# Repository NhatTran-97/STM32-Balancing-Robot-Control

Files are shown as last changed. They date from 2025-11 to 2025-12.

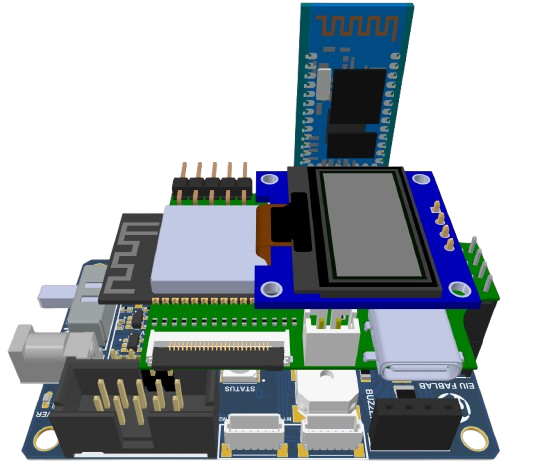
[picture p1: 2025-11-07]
prefix/images/Screenshot_2025-09-14_141622-removebg-preview.png

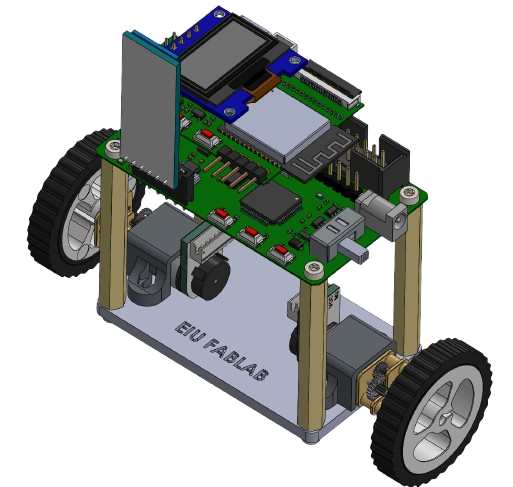
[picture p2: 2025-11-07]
prefix/images/Screenshot_2025-09-14_212536-removebg-preview.png

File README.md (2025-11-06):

# STM32 Self-Balancing Control

A self-balancing robot based on the **STM32 microcontroller**, implementing both **PID** and **LQR** control algorithms.
This project also applies **signal filtering** techniques to improve sensor accuracy and control stability:

* **Moving Average Filter** for encoder smoothing
* **Complementary Filter** for IMU fusion (gyroscope + accelerometer)

---

## 🧭 Overview

This project demonstrates the design of a **self-balancing two-wheel robot** using an STM32 MCU.
It integrates:

* Real-time angle estimation with IMU sensors
* Encoder feedback for wheel speed
* Dual control strategies (PID and LQR)
* Data filtering for smoother, more accurate control
---

## ⚙️ System Architecture / Kiến trúc hệ thống

```
[ Encoder ] ---> [ Moving Average Filter ] ---> [ Wheel Speed ]
                      ↓
[ IMU (Gyro + Accel) ] ---> [ Complementary Filter ] ---> [ Tilt Angle θ, θ_dot ]
                      ↓
            [ PID / LQR Controller ]
                      ↓
             [ PWM Output to Motors ]
```

---

## 🧩 Features

| Module | Description | Mô tả |
| :--- | :--- | :--- |
| **Encoder Filtering** | Moving Average Filter to smooth velocity readings  | Bộ lọc trung bình trượt làm mượt dữ liệu encoder |
| **Angle Estimation**  | Complementary Filter combining gyro & accel | Bộ lọc bổ sung hợp nhất gyro và accelerometer |
| **PID Control** | Classic feedback control for balance | Điều khiển phản hồi cổ điển PID |
| **LQR Control** | Optimal control minimizing system energy | Điều khiển tối ưu hóa năng lượng hệ thống |
| **Visualization** | Serial plotting / Python interface for angle & PWM | Giao diện hiển thị qua Serial/Python để giám sát góc và PWM |

---

## 🧠 Control Algorithms

### 1. PID Control

[
u = K_p e + K_i \int e ,dt + K_d \frac{de}{dt}
]

### 2. LQR Control

[
u = -Kx
]
where ( x = [\theta, \dot{\theta}, v, \dot{v}]^T )

---

## 🔧 Hardware Setup 

| Component | Description |
| :--- | :--- |
| MCU | STM32L476RGT6 series |
| IMU | ICM20948 |
| Motor Driver | STSP240 |
| Encoders | DC motor encoders (e.g., 11 PPR) |
| Power | 2S/3S LiPo battery |
| Frame | Two-wheel balancing chassis |

---

## 📂 Project Structure

```
STM32-Self-Balancing-Control/
├── Core/
│   ├── Src/
│   ├── Inc/
│   └── main.c
├── Drivers/
├── Filters/
│   ├── moving_average.c
│   └── complementary_filter.c
├── Control/
│   ├── pid.c
│   └── lqr.c
├── Utils/
│   └── encoder.c
├── README.md
```

---

## 🧪 Implementation Notes / Ghi chú triển khai

* Sampling period: 10 ms (100 Hz loop)
* Complementary filter α = 0.98
* Moving average window = 10 samples
* PID gains tuned manually via step response
* LQR gains obtained from linearised model in MATLAB

---

## 🧰 Build & Flash

**Toolchain:** STM32CubeIDE / PlatformIO
**Steps:**

1. Clone this repository

   ```bash
   git clone https://github.com/NhatTran-97/STM32-Self-Balancing-Control.git
   ```
2. Open project in STM32CubeIDE
3. Build and flash firmware to STM32 board
4. Connect via UART/USB to monitor data

---

## 🎥 Demo (optional placeholder)

> *Add a GIF or image of the balancing robot here*
>
> Ví dụ: ảnh robot đang tự cân bằng hoặc biểu đồ góc nghiêng.

---

## 📚 References 

* [Complementary Filter explained](https://www.pieter-jan.com/node/11)
* [LQR Design for Inverted Pendulum](https://ctms.engin.umich.edu/CTMS/index.php?example=InvertedPendulum&section=ControlStateSpace)
* STM32Cube HAL documentation
* ICM20948 datasheet

---

**Author:** [NhatTran-97](https://github.com/NhatTran-97)
**License:** MIT License

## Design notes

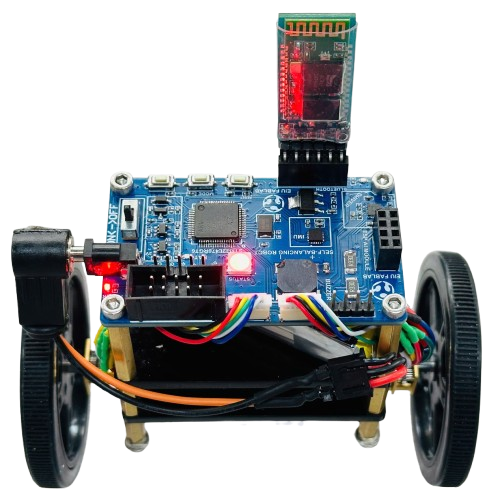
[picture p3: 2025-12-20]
prefix/images/robot_balancing.png

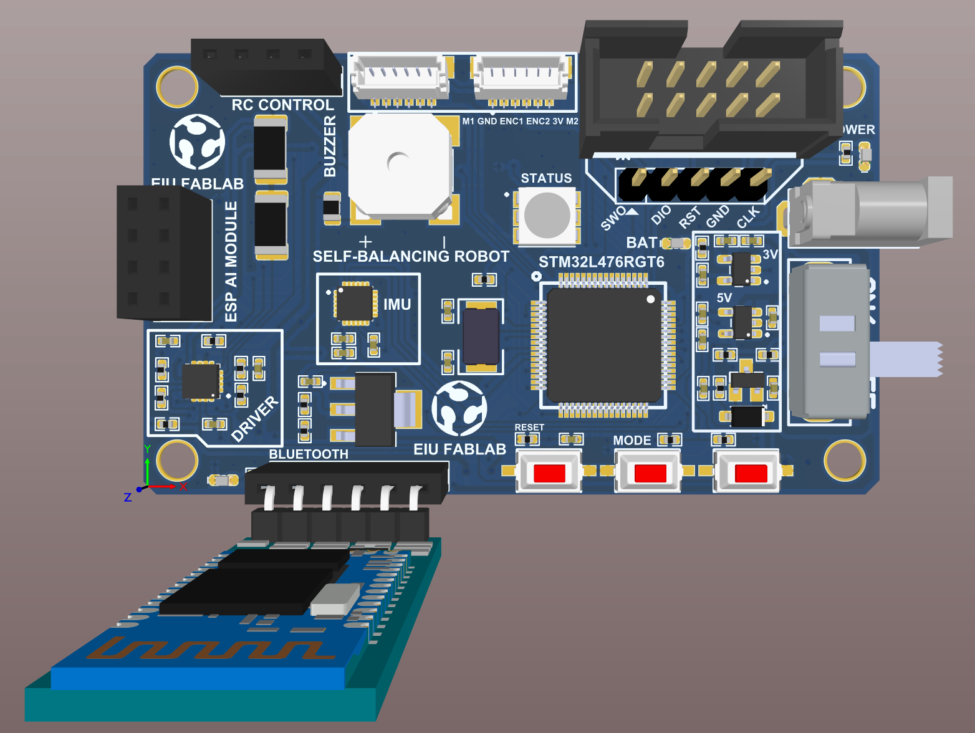
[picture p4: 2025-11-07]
prefix/images/Screenshot 2025-09-14 213541.png

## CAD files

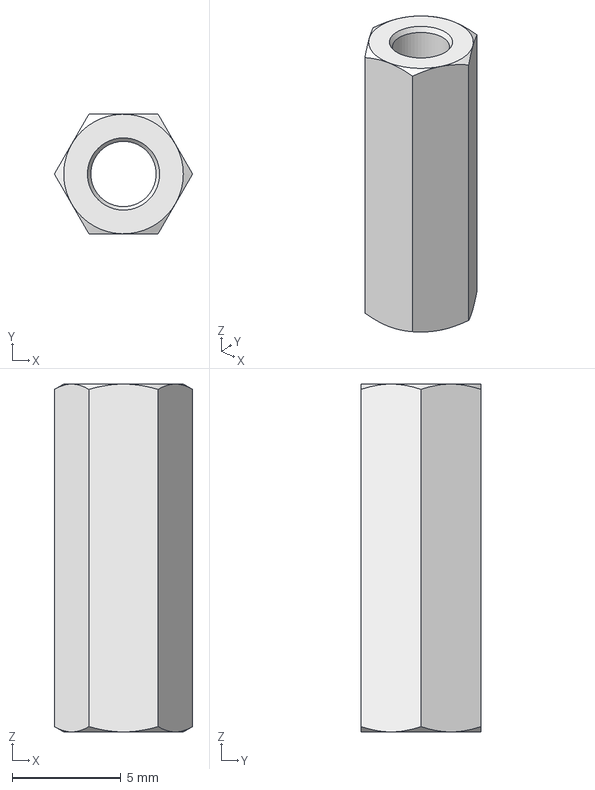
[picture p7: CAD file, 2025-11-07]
3D_Balancing_Robot/hexagonal-spacers-m3-f-f-hex-5-5-1.snapshot.1/hexagonal_spacer_FF_M3_H16_HEX5.5_pass_through.step
6.36 x 5.51 x 16.0 mm

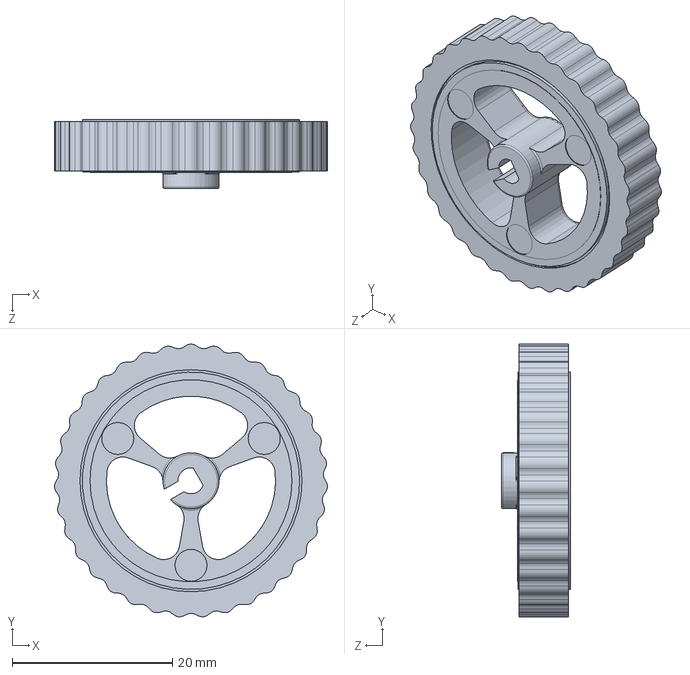
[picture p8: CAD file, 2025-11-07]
3D_Balancing_Robot/llanta-para-motor-n20-32x7mm-blanca-1.snapshot.1/Llanta.SLDPRT
34.1 x 34.0 x 8.65 mm

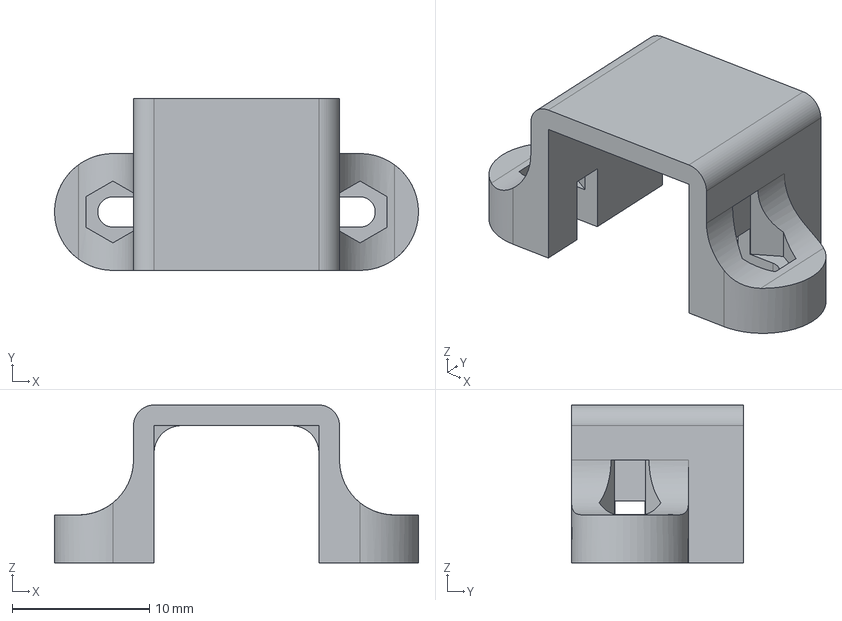
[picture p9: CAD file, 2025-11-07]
3D_Balancing_Robot/n20-motor-mount-2.snapshot.1/motor mount-Body.step
26.5 x 12.5 x 11.5 mm

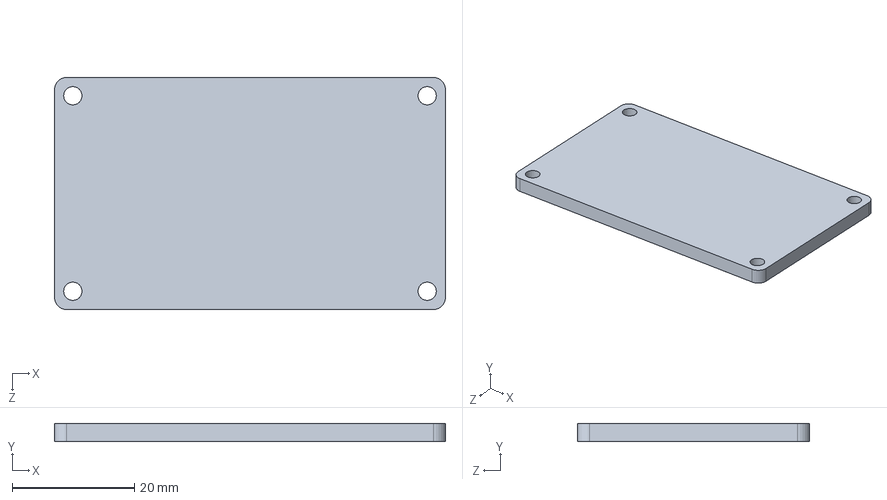
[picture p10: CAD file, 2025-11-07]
3D_Balancing_Robot/Part2.SLDPRT
64.0 x 3.00 x 38.0 mm

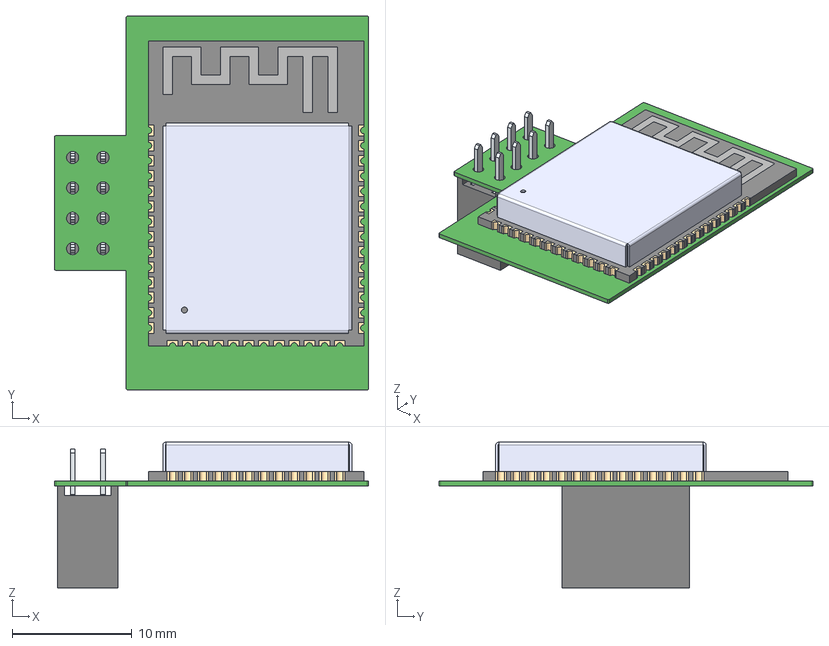
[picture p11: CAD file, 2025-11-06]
PCB_ESP32_Dev/3D/ESP32_DEV.step
26.3 x 31.3 x 12.2 mm
Board
6130xx21821_PIN x 8

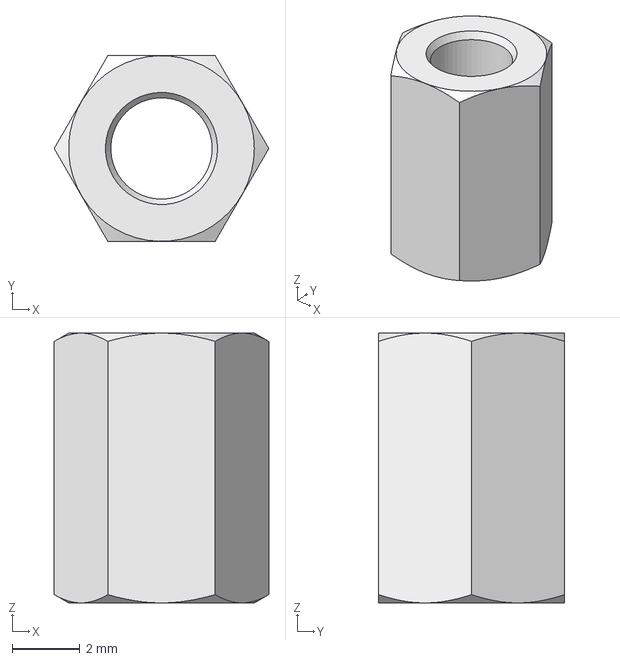
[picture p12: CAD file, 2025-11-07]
3D_Balancing_Robot/hexagonal-spacers-m3-f-f-hex-5-5-1.snapshot.1/hexagonal_spacer_FF_M3_H08_HEX5.5_pass_through.step
6.36 x 5.51 x 8.00 mm

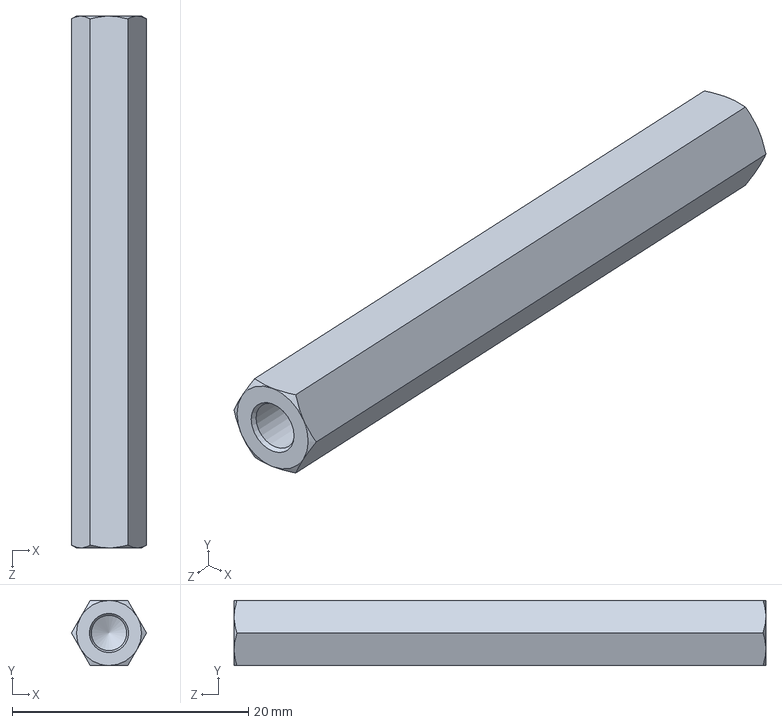
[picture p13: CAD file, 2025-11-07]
3D_Balancing_Robot/hexagonal_spacer_FF_M3_H45_HEX5.5_FTD0.SLDPRT
6.36 x 5.51 x 45.0 mm

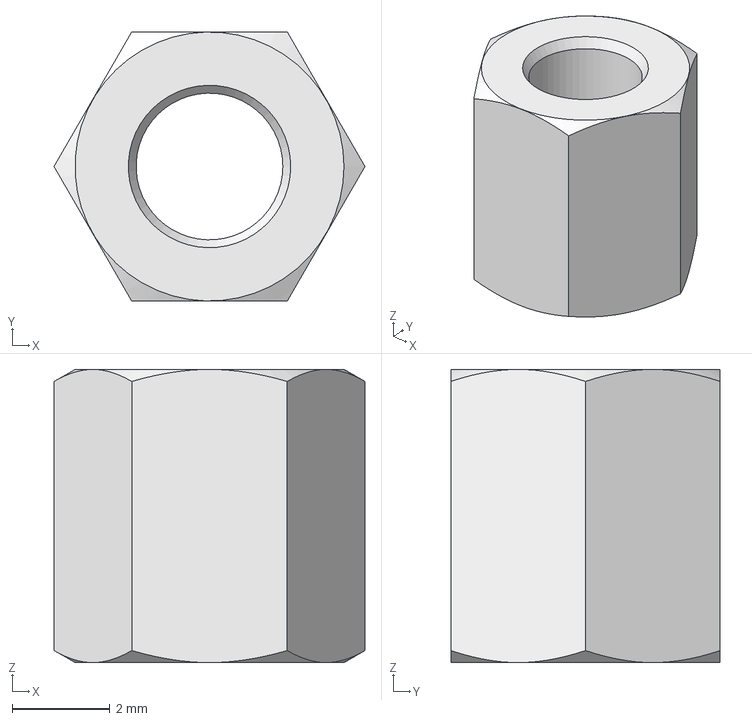
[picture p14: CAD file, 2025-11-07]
3D_Balancing_Robot/hexagonal-spacers-m3-f-f-hex-5-5-1.snapshot.1/hexagonal_spacer_FF_M3_H06_HEX5.5_pass_through.step
6.36 x 5.51 x 6.00 mm

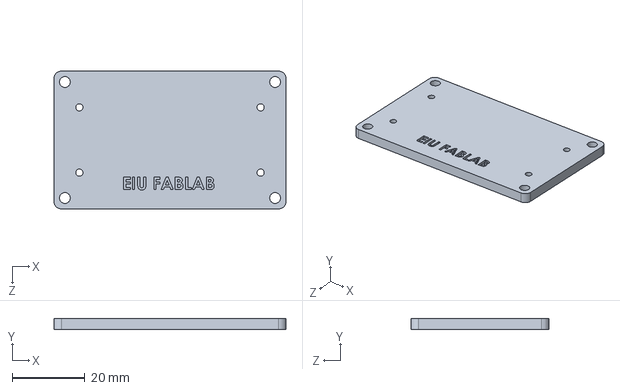
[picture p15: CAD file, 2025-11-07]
3D_Balancing_Robot/Part1.SLDPRT
64.0 x 3.00 x 38.0 mm

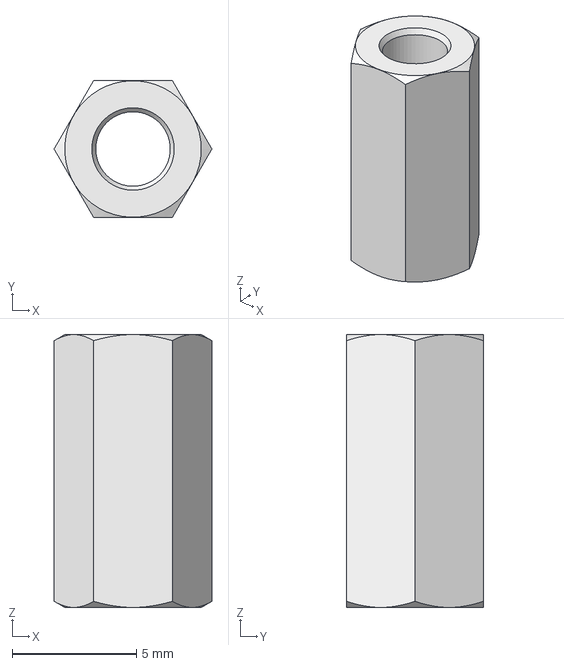
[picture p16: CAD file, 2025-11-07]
3D_Balancing_Robot/hexagonal-spacers-m3-f-f-hex-5-5-1.snapshot.1/hexagonal_spacer_FF_M3_H11_HEX5.5_pass_through.step
6.36 x 5.51 x 11.0 mm

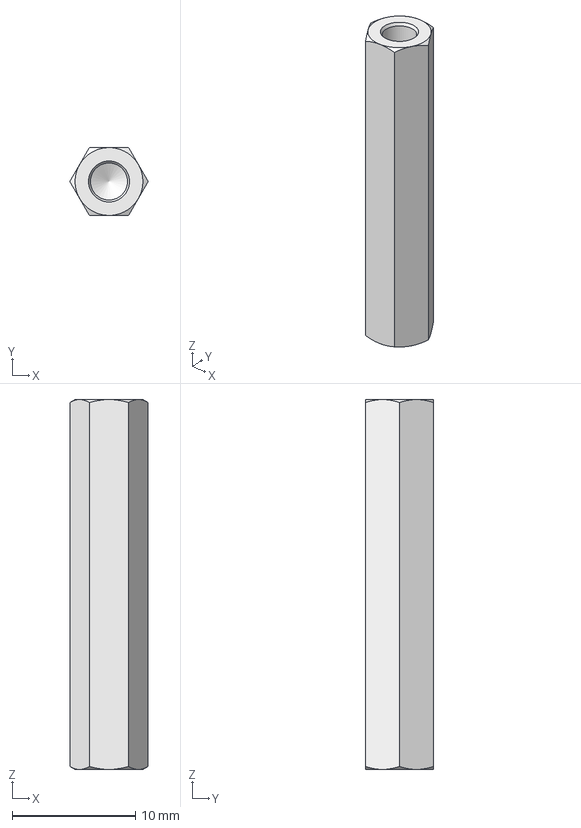
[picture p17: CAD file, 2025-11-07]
3D_Balancing_Robot/hexagonal-spacers-m3-f-f-hex-5-5-1.snapshot.1/hexagonal_spacer_FF_M3_H30_HEX5.5_FTD10.step
6.36 x 5.51 x 30.0 mm

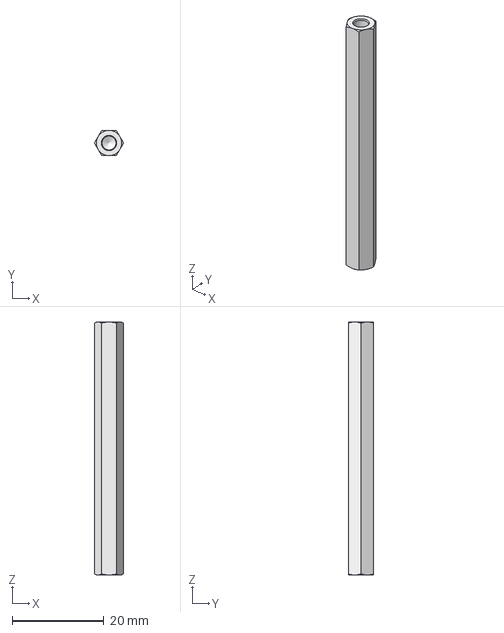
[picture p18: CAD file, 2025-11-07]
3D_Balancing_Robot/hexagonal-spacers-m3-f-f-hex-5-5-1.snapshot.1/hexagonal_spacer_FF_M3_H55_HEX5.5_FTD10.step
6.36 x 5.51 x 55.0 mm

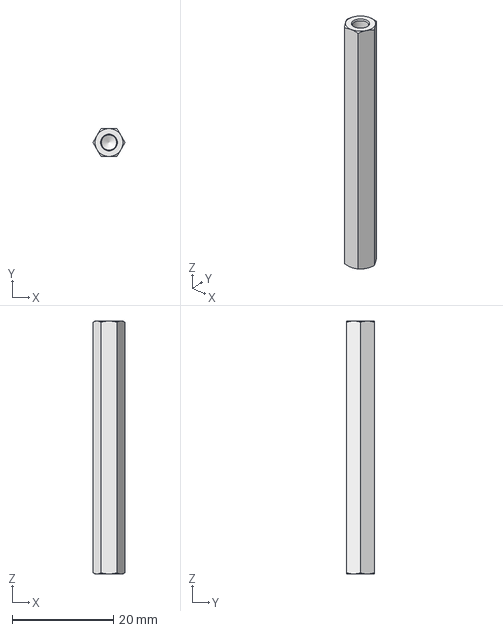
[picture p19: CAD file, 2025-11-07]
3D_Balancing_Robot/hexagonal-spacers-m3-f-f-hex-5-5-1.snapshot.1/hexagonal_spacer_FF_M3_H50_HEX5.5_FTD10.step
6.36 x 5.51 x 50.0 mm

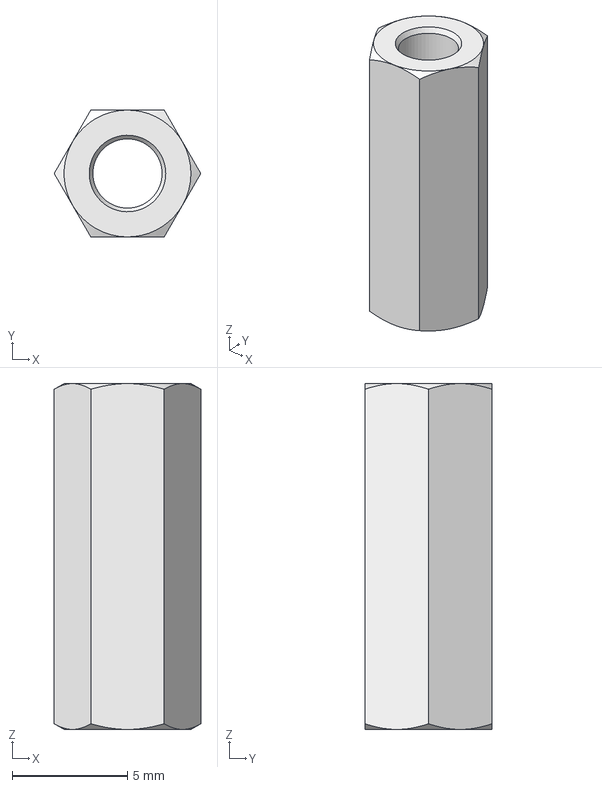
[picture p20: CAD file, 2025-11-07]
3D_Balancing_Robot/hexagonal-spacers-m3-f-f-hex-5-5-1.snapshot.1/hexagonal_spacer_FF_M3_H15_HEX5.5_pass_through.step
6.36 x 5.51 x 15.0 mm

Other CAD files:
3D_Balancing_Robot/llanta-para-motor-n20-32x7mm-blanca-1.snapshot.1/Llanta1.SLDPRT
3D_Balancing_Robot/hexagonal_spacer_FF_M3_H45_HEX5.5_FTD10.SLDPRT
3D_Balancing_Robot/hexagonal-spacers-m3-f-f-hex-5-5-1.snapshot.1/hexagonal_spacer_FF_M3_H18_HEX5.5_pass_through.step
3D_Balancing_Robot/hexagonal-spacers-m3-f-f-hex-5-5-1.snapshot.1/hexagonal_spacer_FF_M3_H45_HEX5.5_FTD10.step
3D_Balancing_Robot/hexagonal-spacers-m3-f-f-hex-5-5-1.snapshot.1/hexagonal_spacer_FF_M3_H04_HEX5.5_pass_through.step
3D_Balancing_Robot/hexagonal-spacers-m3-f-f-hex-5-5-1.snapshot.1/hexagonal_spacer_FF_M3_H05_HEX5.5_pass_through.step
3D_Balancing_Robot/hexagonal-spacers-m3-f-f-hex-5-5-1.snapshot.1/hexagonal_spacer_FF_M3_H07_HEX5.5_pass_through.step
3D_Balancing_Robot/hexagonal-spacers-m3-f-f-hex-5-5-1.snapshot.1/hexagonal_spacer_FF_M3_H09_HEX5.5_pass_through.step
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

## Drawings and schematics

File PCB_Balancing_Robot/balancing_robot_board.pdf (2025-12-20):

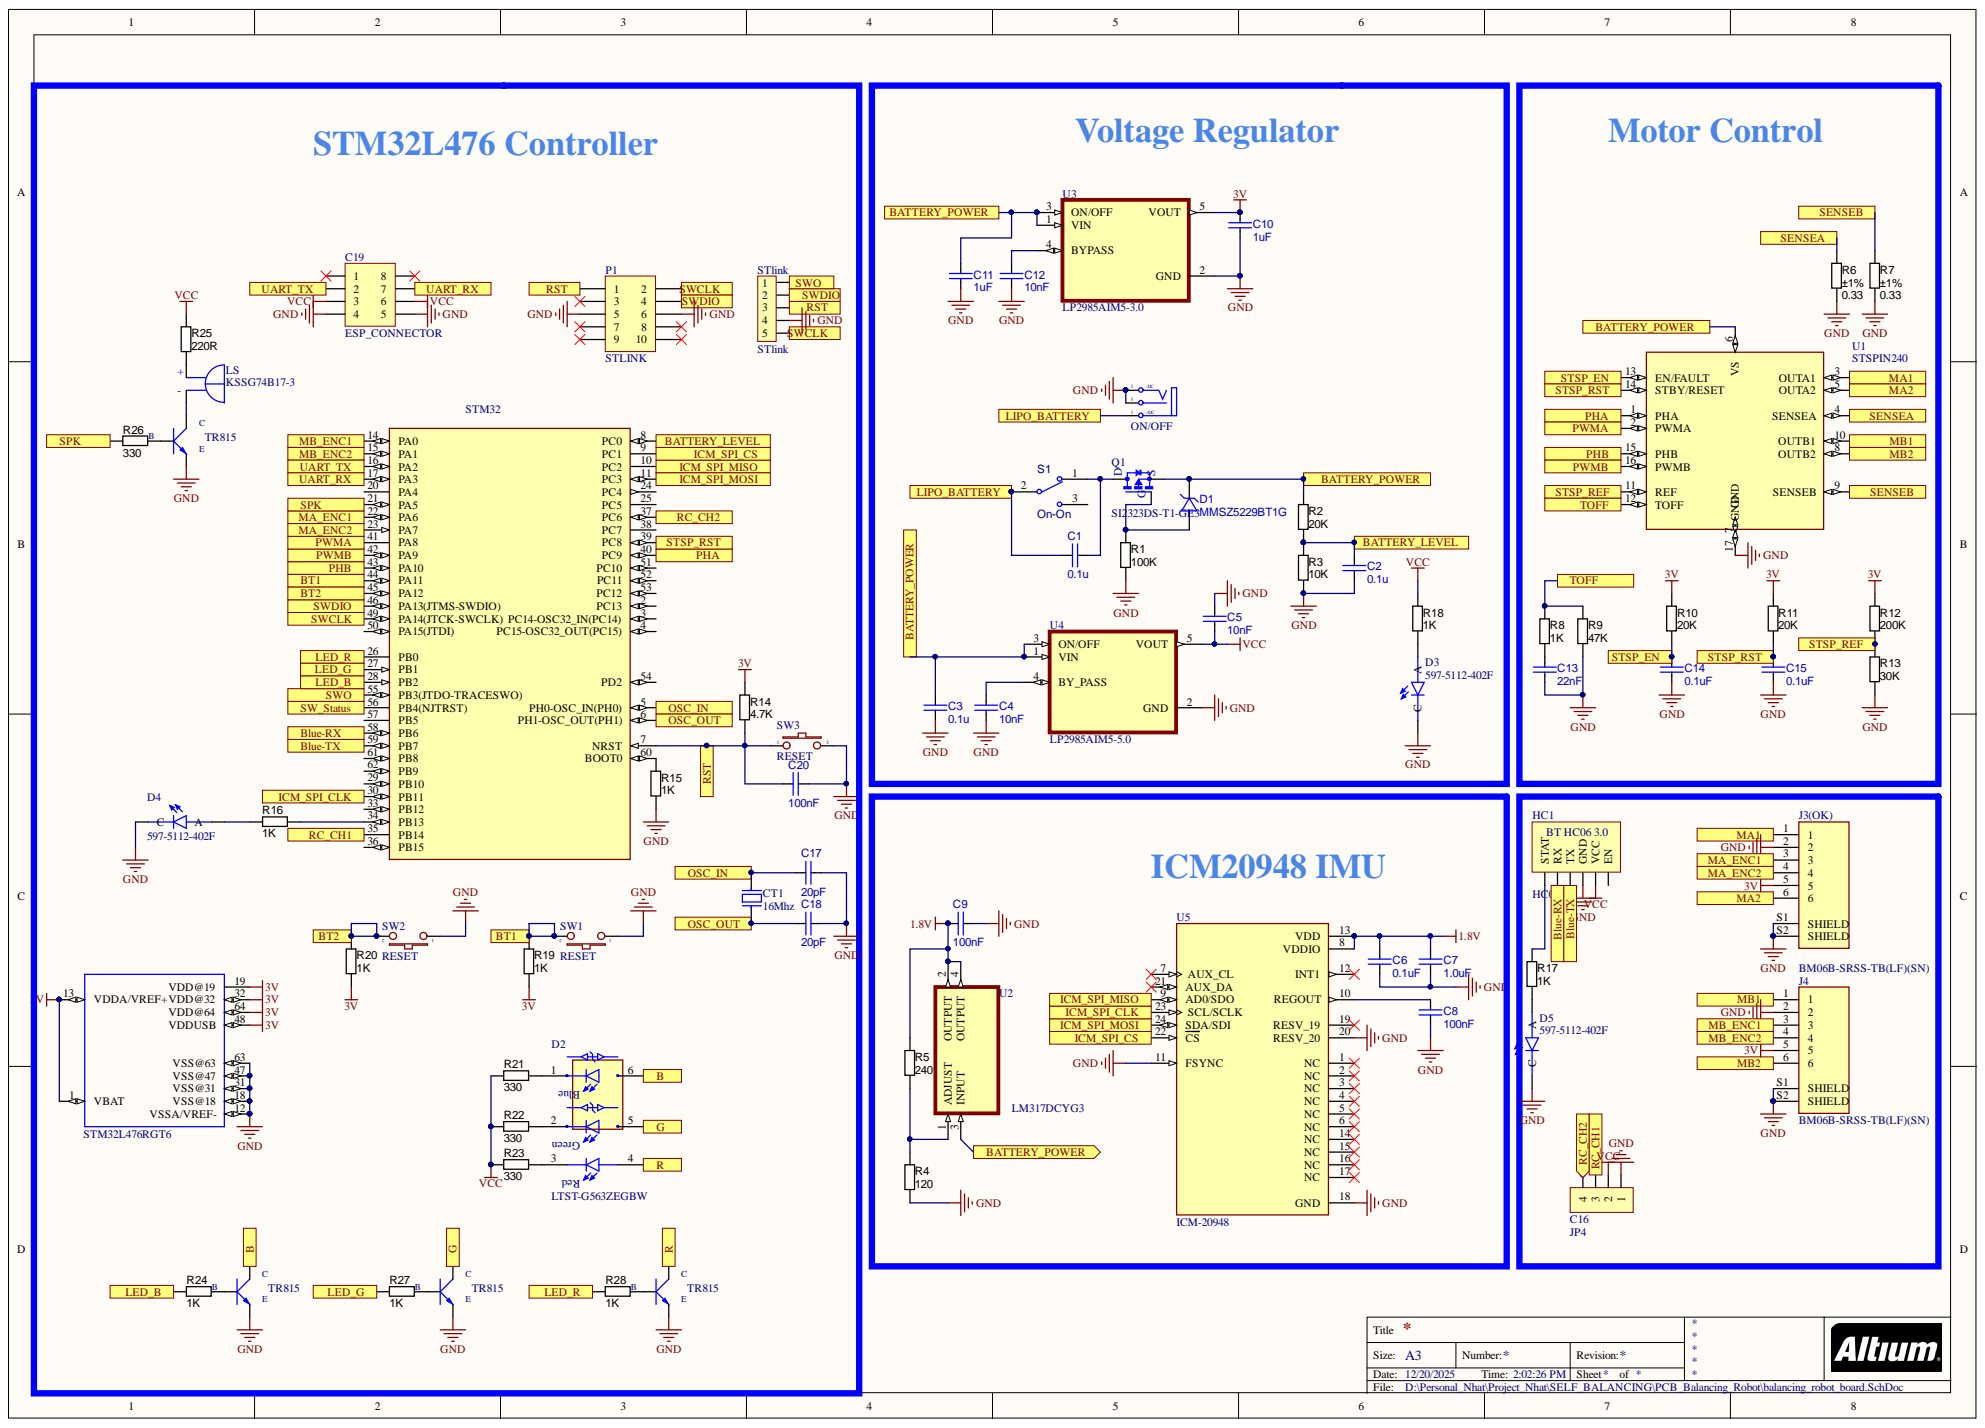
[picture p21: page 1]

STSP_EN | STBY/RESET 14 | MA1
STSP_RST | PHA 1 | MA2

VIN 1

LED_G | PB2 28
LED_B | PB3(JTDO-TRACESWO) 55
SWO | PB4(NJTRST) 56

Blue-RX | PB7 59

MA_ENC1 | 4 4

BM06B-SRSS-TB(LF)(SN)

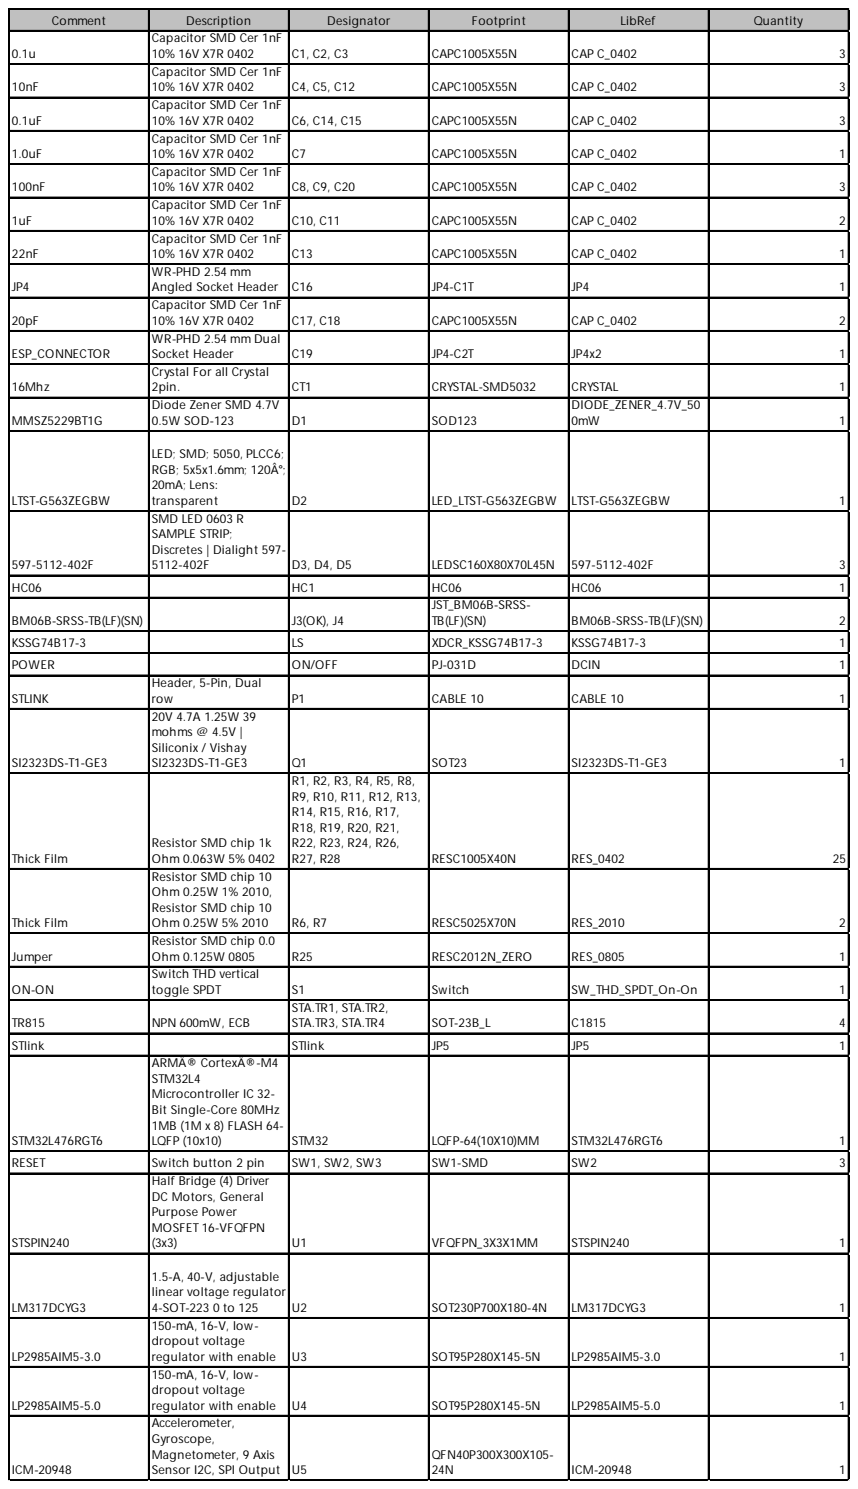
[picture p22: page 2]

Comment | Description | Designator | Footprint | LibRef | Quantity

0.1u | Capacitor SMD Cer 1nF 10% 16V X7R 0402 | C1, C2, C3 | CAPC1005X55N | CAP C_0402 | 3

10nF | Capacitor SMD Cer 1nF 10% 16V X7R 0402 | C4, C5, C12 | CAPC1005X55N | CAP C_0402 | 3

0.1uF | Capacitor SMD Cer 1nF 10% 16V X7R 0402 | C6, C14, C15 | CAPC1005X55N | CAP C_0402 | 3

1.0uF | Capacitor SMD Cer 1nF 10% 16V X7R 0402 | C7 | CAPC1005X55N | CAP C_0402 | 1

100nF | Capacitor SMD Cer 1nF 10% 16V X7R 0402 | C8, C9, C20 | CAPC1005X55N | CAP C_0402 | 3

1uF | Capacitor SMD Cer 1nF 10% 16V X7R 0402 | C10, C11 | CAPC1005X55N | CAP C_0402 | 2

22nF | Capacitor SMD Cer 1nF 10% 16V X7R 0402 | C13 | CAPC1005X55N | CAP C_0402 | 1

JP4 | WR-PHD 2.54 mm Angled Socket Header | C16 | JP4-C1T | JP4 | 1

20pF | Capacitor SMD Cer 1nF 10% 16V X7R 0402 | C17, C18 | CAPC1005X55N | CAP C_0402 | 2

ESP_CONNECTOR | WR-PHD 2.54 mm Dual Socket Header | C19 | JP4-C2T | JP4x2 | 1

16Mhz | Crystal For all Crystal 2pin. | CT1 | CRYSTAL-SMD5032 | CRYSTAL | 1

MMSZ5229BT1G | Diode Zener SMD 4.7V 0.5W SOD-123 | D1 | SOD123 | DIODE_ZENER_4.7V_50 0mW | 1

LTST-G563ZEGBW | LED; SMD; 5050, PLCC6; RGB; 5x5x1.6mm; 120Â°; 20mA; Lens: transparent | D2 | LED_LTST-G563ZEGBW | LTST-G563ZEGBW | 1

597-5112-402F | SMD LED 0603 R SAMPLE STRIP; Discretes | Dialight 597-5112-402F | D3, D4, D5 | LEDSC160X80X70L45N | 597-5112-402F | 3

HC06 | | HC1 | HC06 | HC06 | 1
BM06B-SRSS-TB(LF)(SN) | | J3(OK), J4 | JST_BM06B-SRSS-TB(LF)(SN) | BM06B-SRSS-TB(LF)(SN) | 2

KSSG74B17-3 | | LS | XDCR_KSSG74B17-3 | KSSG74B17-3 | 1

POWER | | ON/OFF | PJ-031D | DCIN | 1
STLINK | Header, 5-Pin, Dual row | P1 | CABLE 10 | CABLE 10 | 1

SI2323DS-T1-GE3 | 20V 4.7A 1.25W 39 mohms @ 4.5V | Siliconix / Vishay SI2323DS-T1-GE3 | Q1 | SOT23 | SI2323DS-T1-GE3 | 1

Thick Film | Resistor SMD chip 1k Ohm 0.063W 5% 0402 | R1, R2, R3, R4, R5, R8, R9, R10, R11, R12, R13, R14, R15, R16, R17, R18, R19, R20, R21, R22, R23, R24, R26, R27, R28 | RESC1005X40N | RES_0402 | 25

Thick Film | Resistor SMD chip 10 Ohm 0.25W 1% 2010, Resistor SMD chip 10 Ohm 0.25W 5% 2010 | R6, R7 | RESC5025X70N | RES_2010 | 2

Jumper | Resistor SMD chip 0.0 Ohm 0.125W 0805 | R25 | RESC2012N_ZERO | RES_0805 | 1

ON-ON | Switch THD vertical toggle SPDT | S1 | Switch | SW_THD_SPDT_On-On | 1

TR815 | NPN 600mW, ECB | STA.TR1, STA.TR2, STA.TR3, STA.TR4 | SOT-23B_L | C1815 | 4

STlink | | STlink | JP5 | JP5 | 1
STM32L476RGT6 | ARMÂ® CortexÂ®-M4 STM32L4 Microcontroller IC 32-Bit Single-Core 80MHz 1MB (1M x 8) FLASH 64-LQFP (10x10) | STM32 | LQFP-64(10X10)MM | STM32L476RGT6 | 1

RESET | Switch button 2 pin | SW1, SW2, SW3 | SW1-SMD | SW2 | 3
STSPIN240 | Half Bridge (4) Driver DC Motors, General Purpose Power MOSFET 16-VFQFPN (3x3) | U1 | VFQFPN_3X3X1MM | STSPIN240 | 1

LM317DCYG3 | 1.5-A, 40-V, adjustable linear voltage regulator 4-SOT-223 0 to 125 | U2 | SOT230P700X180-4N | LM317DCYG3 | 1

LP2985AIM5-3.0 | 150-mA, 16-V, low-dropout voltage regulator with enable | U3 | SOT95P280X145-5N | LP2985AIM5-3.0 | 1

LP2985AIM5-5.0 | 150-mA, 16-V, low-dropout voltage regulator with enable | U4 | SOT95P280X145-5N | LP2985AIM5-5.0 | 1

ICM-20948 | Accelerometer, Gyroscope, Magnetometer, 9 Axis Sensor I2C, SPI Output | U5 | QFN40P300X300X105-24N | ICM-20948 | 1

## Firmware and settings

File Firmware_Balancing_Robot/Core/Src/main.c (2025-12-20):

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
/* Includes ------------------------------------------------------------------*/
#include "main.h"

/* USER CODE BEGIN Includes */
#include "motor_control.h"
#include "stdio.h"
#include "motor_encoder.h"
#include "pid_control.h"
#include "icm_20948.h"
#include "arm_math.h"
#include "imu_data.h"
#include "euler_angles.h"
#include "lqr.h"
#include "buzzer.h"
#include "uart.h"
#include "telemetry.h"
#include "battery.h"
#include "rgb.h"
//#include "moving_average_filter.h"


/* USER CODE END Includes */

/* USER CODE BEGIN PM */
uint8_t status;

/* USER CODE END PM */

ADC_HandleTypeDef hadc1;
DMA_HandleTypeDef hdma_adc1;

SPI_HandleTypeDef hspi2;
DMA_HandleTypeDef hdma_spi2_rx;
DMA_HandleTypeDef hdma_spi2_tx;

TIM_HandleTypeDef htim1;
TIM_HandleTypeDef htim2;
TIM_HandleTypeDef htim3;
TIM_HandleTypeDef htim4;
TIM_HandleTypeDef htim8;

UART_HandleTypeDef huart2;
DMA_HandleTypeDef hdma_usart2_rx;
DMA_HandleTypeDef hdma_usart2_tx;

/* USER CODE BEGIN PV */
int dumb_data = 0;
volatile  uint16_t adc_battery;

float robot_battery;


const static motor_inst motor_a = {.htim_motor = &htim1,
																	 .htim_motor_ch = TIM_CHANNEL_1,
																	 .mdir_pin_number = PHA_Pin,
																	 .mdir_pin_port = PHA_GPIO_Port,
																	 .rst_pin_number = STSP_RST_Pin,
																	 .rst_pin_port = STSP_RST_GPIO_Port};
const static motor_inst motor_b = {.htim_motor = &htim1,
																	 .htim_motor_ch = TIM_CHANNEL_2,
																	 .mdir_pin_number = PHB_Pin,
																	 .mdir_pin_port = PHB_GPIO_Port,
																	 .rst_pin_number = STSP_RST_Pin,
																	 .rst_pin_port = STSP_RST_GPIO_Port};

																	 

static encoder_inst motora_enc = {.first_time = 0,
																	.htim_encoder = &htim3,
																	.last_counter_value = 0,
																	.position = 0,
																	.timer_period = 0.002,
																	.velocity = 0};

																	
static encoder_inst motorb_enc = {.first_time = 0,
																	.htim_encoder = &htim2,
																	.last_counter_value = 0,
																	.position = 0,
																	.timer_period = 0.002,
																	.velocity = 0};
static pid_instance mota_pid = {.d_gain = 0,
                                .error_integral = 0,
																.i_gain = 1.0f,
																.integral_max = 5000,
																.last_error = 0,
																.output = 0,
																.p_gain = 10.0f,
																.pid_max = 100,
																.sam_rate = 100};

static pid_instance mot_rotation_pid = {.d_gain = 0.5,
                                .error_integral = 0,
																.i_gain = 0.0f,
																.integral_max = 5,
																.last_error = 0,
																.output = 0,
																.p_gain = 2.0f,
																.pid_max = 30,
																.sam_rate = 500};

																
																
				
uint32_t timer_counter;
uint8_t timer_flag,mag_timer_flag;
float temp_velocity, filter_out;
uint8_t timer_flag;
mov_aver_instance temp_filter;
int32_t duty_cycle_ch1, duty_cycle_ch2;
																
uint8_t address, data;
															
int16_t a_x, a_y, a_z, g_x, g_y, g_z;
icm_20948_data icm_data;
																
																
int32_t sum_gyro_x, sum_gyro_y, sum_gyro_z;
int16_t mag_x, mag_y, mag_z;
																
volatile uint8_t telem_div = 0;
volatile bool telemetry_pending = false;													
																
																
// min / max magnetometer
float mag_x_min =  1e9f;
float mag_y_min =  1e9f;
float mag_z_min =  1e9f;

float mag_x_max = -1e9f;
float mag_y_max = -1e9f;
float mag_z_max = -1e9f;


// d? d?m th?i gian calibrate
uint32_t mag_sample_count = 0;



float mag_bias_x, mag_bias_y, mag_bias_z;
float mag_scale_x, mag_scale_y, mag_scale_z;


imu_norm imu_norm_data;
euler_angles euler_temp,euler_angles_robot, euler_angles_old;																
StateTypeDef robot_state;
RGB        rgb;

int16_t counter_time;

float force;



//uint8_t rx1_buf[256];
//volatile uint16_t rx_len = 0;
//volatile uint8_t rx_ready = 0;

//static float32_t reference1, reference2;


/* USER CODE END PV */

void SystemClock_Config(void);
static void MX_GPIO_Init(void);
static void MX_DMA_Init(void);
static void MX_TIM1_Init(void);
static void MX_TIM2_Init(void);
static void MX_TIM3_Init(void);
static void MX_TIM4_Init(void);
static void MX_TIM8_Init(void);
static void MX_SPI2_Init(void);
static void MX_ADC1_Init(void);
static void MX_USART2_UART_Init(void);
/**
  * @brief  The application entry point.
  * @retval int
  */
int main(void)
{

  /* USER CODE BEGIN 1 */
//	uint8_t address, data;
	

  /* USER CODE END 1 */

  /* MCU Configuration--------------------------------------------------------*/

  /* Reset of all peripherals, Initializes the Flash interface and the Systick. */
  HAL_Init();

  /* USER CODE BEGIN Init */
	//icm_20948_data icm_data;

  /* USER CODE END Init */

  /* Configure the system clock */
  SystemClock_Config();

  /* Initialize all configured peripherals */
  MX_GPIO_Init();
  MX_DMA_Init();
  MX_TIM1_Init();
  MX_TIM2_Init();
  MX_TIM3_Init();
  MX_TIM4_Init();
  MX_TIM8_Init();
  MX_SPI2_Init();
  MX_ADC1_Init();
  MX_USART2_UART_Init();
  /* USER CODE BEGIN 2 */
	
	Buzzer_Init();
	UART_Init();
	Telemetry_Init();

	 rgb_init(&rgb, GPIOB, RGB_R_Pin, RGB_G_Pin, RGB_B_Pin);
  //UART_SendString("UART ready\r\n");
	
	HAL_Delay(100);




	// Start PWM in channels 2 and 3
	HAL_TIM_PWM_Start(&htim1, TIM_CHANNEL_1);
	HAL_TIM_PWM_Start(&htim1, TIM_CHANNEL_2);
	
	enable_motor((motor_inst*)&motor_a);
	enable_motor((motor_inst*)&motor_b);

	HAL_Delay(1000);
	reset_encoder(&motora_enc);
	reset_encoder(&motorb_enc);
	reset_pid(&mota_pid);
	icm_20948_init();
	icm_20948_read_data(&icm_data);
	sensor2imu(icm_data, &imu_norm_data);
	complementary_filter_euler(imu_norm_data,  &euler_angles_robot);
	euler_angles_old = euler_angles_robot;

  /* USER CODE END 2 */

  /* Infinite loop */
  /* USER CODE BEGIN WHILE */
  while (1)
  {
    /* USER CODE END WHILE */
		

    /* USER CODE BEGIN 3 */
		robot_battery = Battery_GetVbat();
		uint8_t b;
    while (UART_ReadByte(&b))
    {
        Telemetry_RxByte(b);   
    }
		if (telemetry_pending)
    {
        telemetry_pending = false;
        Telemetry_SendEuler(&euler_angles_robot);
    }
		
		rgb_setcolor(&rgb, RGB_PURPLE);
		if(timer_flag == 1) // 2ms
		{
		
			timer_flag = 0;
			get_encoder_speed(&motora_enc);
			get_encoder_speed(&motorb_enc);
			
			//temp_velocity = motora_enc.velocity;
		//	apply_average_filter(&temp_filter, motora_enc.velocity, &filter_out);
			//apply_pid(&mota_pid, 5 - temp_velocity); // setpoint = 5
			//set_speed_open((motor_inst*)&motor_a, mota_pid.output);
			
		//	set_speed_open((motor_inst*)&motor_a, 0);
			
		//	set_speed_open((motor_inst*)&motor_a, (duty_cycle_ch1 / 100));
		//	set_speed_open((motor_inst*)&motor_b, (duty_cycle_ch2 / 100));
		//	dumb_data++;
			
				icm_20948_read_data(&icm_data);
				sensor2imu(icm_data, &imu_norm_data);
				complementary_filter_euler(imu_norm_data, &euler_angles_robot);
			   if (++telem_div >= 10)   // 50Hz,    // 5 * 2ms = 10ms = 100Hz
				{
						telem_div = 0;
						telemetry_pending = true;
				}
			 // apply_pid(&mot_rotation_pid, motora_enc.position - motorb_enc.position);
			 robot_state.angle = euler_angles_robot.pitch;
			 robot_state.angle_vel = robot_state.angle_vel * 0.8f + 0.2f * (euler_angles_robot.pitch - euler_angles_old.pitch) * SAMPLE_RATE;
			 
			 robot_state.position = (motora_enc.position + motorb_enc.position) / 2 ;
			 robot_state.velocity = (motora_enc.velocity + motorb_enc.velocity) / 2 ;
//			 
//			 apply_force((motor_inst*)&motor_a, force / 2, motora_enc.velocity);
//			 apply_lqr(robot_state, &force);
//			 

//			if (euler_angles_robot.pitch < 1.0 && euler_angles_robot.pitch > -1.0)
//			{
//			  apply_force((motor_inst*)&motor_a, force / 2, motora_enc.velocity);
//			  apply_force((motor_inst*)&motor_b, force / 2, motorb_enc.velocity);
//			}
//			else
//			{
//			 set_speed_zero((motor_inst*)&motor_a);
//			 set_speed_zero((motor_inst*)&motor_b);
//			}
			
//			if (euler_angles_robot.pitch < 1.0 && euler_angles_robot.pitch > -1.0)
//			{
//			  apply_force((motor_inst*)&motor_a, force / 2 - mot_rotation_pid.output / 2, motora_enc.velocity);
//			  apply_force((motor_inst*)&motor_b, force / 2 + mot_rotation_pid.output / 2, motorb_enc.velocity);
//			}
//			else
//			{
//			 set_speed_zero((motor_inst*)&motor_a);
//			 set_speed_zero((motor_inst*)&motor_b);
//			}
			
			
			euler_angles_old = euler_angles_robot;
			
			
		
		
  }
  }
  /* USER CODE END 3 */
}

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
/* USER CODE BEGIN 4 */

//void HAL_TIM_PeriodElapsedCallback(TIM_HandleTypeDef *htim) // 10ms
//{
//	if(htim == &htim4)
//	{
//		timer_flag = 1;
//	}
//		if(htim == &htim5)
//	{
//		mag_timer_flag = 1;
//	}
//}

void HAL_TIM_PeriodElapsedCallback(TIM_HandleTypeDef *htim)
{
    if (htim->Instance == TIM4)
    {
        timer_flag = 1;
    }
    else if (htim->Instance == TIM5)
    {
        mag_timer_flag = 1;
    }
}




/* USER CODE END 4 */
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


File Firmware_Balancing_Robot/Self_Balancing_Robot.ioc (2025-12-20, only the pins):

Mcu.UserName=STM32L476RGTx
PA0.Signal=S_TIM2_CH1
PA1.Signal=S_TIM2_CH2
PA10.GPIO_Label=PHB
PA10.Signal=GPIO_Output
PA11.GPIO_Label=ENTER
PA11.Signal=GPIO_Input
PA12.GPIO_Label=MODE
PA12.Signal=GPIO_Input
PA2.Signal=USART2_TX
PA3.Signal=USART2_RX
PA5.Signal=TIM8_CH1N
PA6.Signal=S_TIM3_CH1
PA7.Signal=S_TIM3_CH2
PA8.GPIO_Label=PWMA
PA8.Signal=S_TIM1_CH1
PA9.GPIO_Label=PWMB
PA9.Signal=S_TIM1_CH2
PB0.GPIO_Label=RGB_R
PB0.Signal=GPIO_Output
PB1.GPIO_Label=RGB_G
PB1.Signal=GPIO_Output
PB10.Signal=SPI2_SCK
PB14.GPIO_Label=RC_CH2
PB14.Signal=S_TIM15_CH1
PB2.GPIO_Label=RGB_B
PB2.Signal=GPIO_Output
PC0.Signal=ADCx_IN1
PC1.GPIO_Label=SPI_CS
PC1.Signal=GPIO_Output
PC2.Signal=SPI2_MISO
PC3.Signal=SPI2_MOSI
PC6.Signal=S_TIM8_CH1
PC8.GPIO_Label=STSP_RST
PC8.Signal=GPIO_Output
PC9.GPIO_Label=PHA
PC9.Signal=GPIO_Output

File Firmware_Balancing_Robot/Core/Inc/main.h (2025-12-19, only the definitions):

#define SPI_CS_Pin GPIO_PIN_1
#define SPI_CS_GPIO_Port GPIOC
#define RGB_R_Pin GPIO_PIN_0
#define RGB_R_GPIO_Port GPIOB
#define RGB_G_Pin GPIO_PIN_1
#define RGB_G_GPIO_Port GPIOB
#define RGB_B_Pin GPIO_PIN_2
#define RGB_B_GPIO_Port GPIOB
#define RC_CH2_Pin GPIO_PIN_14
#define RC_CH2_GPIO_Port GPIOB
#define STSP_RST_Pin GPIO_PIN_8
#define STSP_RST_GPIO_Port GPIOC
#define PHA_Pin GPIO_PIN_9
#define PHA_GPIO_Port GPIOC
#define PWMA_Pin GPIO_PIN_8
#define PWMA_GPIO_Port GPIOA
#define PWMB_Pin GPIO_PIN_9
#define PWMB_GPIO_Port GPIOA
#define PHB_Pin GPIO_PIN_10
#define PHB_GPIO_Port GPIOA
#define ENTER_Pin GPIO_PIN_11
#define ENTER_GPIO_Port GPIOA
#define MODE_Pin GPIO_PIN_12
#define MODE_GPIO_Port GPIOA

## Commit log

2025-11-06 Add Balancing Robot Control
    [ESP32_DEV.PrjPCB, ESP32_DEV.SchDoc, ESP32_DEV.step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]
2025-11-07 Added 3D design
    [Llanta.SLDPRT, Llanta1.SLDPRT, Part1.SLDPRT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]
2025-12-19 Updated firmware
    [ESP32_DEV.PcbDoc, ESP32_DEV.SchDoc, balancing_robot_board.PcbDoc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]

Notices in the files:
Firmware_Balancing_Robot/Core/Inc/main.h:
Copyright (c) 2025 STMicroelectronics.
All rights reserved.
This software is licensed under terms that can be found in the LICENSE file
